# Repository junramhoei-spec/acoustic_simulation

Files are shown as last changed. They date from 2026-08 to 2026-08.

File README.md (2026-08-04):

# 🔊 Acoustic Shape Reconstruction V2 (음향 기반 컵 형상 역추적 프로젝트)

이 프로젝트는 **물 채움 시 수위 변화에 따른 음향 공명 주파수(Dip Spectrum / Ratio Transfer Function)** 데이터를 기반으로 컵의 **높이($) 및 3D 반지름 프로파일((z)$)**을 역추적하는 딥러닝 프레임워크입니다.

---

## 🌟 주요 기능 (Key Features)

1. **순방향 음향 공명 탐색기 (Forward Explorer)**
   - Transfer Matrix Method (TMM) 음향 관 모델링 기반 딥 스펙트럼 합성
   - 물 주입 시퀀스에 따른 음향 워터폴 스펙트로그램 시각화
2. **전문가 결합 모델 (Ensemble Prediction)**
   - 높이 전문가 ($ Expert: 
nn_sline_nodetach_bestH.pt)
   - 반지름 전문가 ($ Expert: 
nn_sline_uni.pt)
   - 25개 10mm 슬롯 피치 등가반지름 계단 프로파일 복원
3. **20종 실측 세션 자동 일괄 평가**
   - 실측 데이터셋 자동 로드 및 실시간 역추정
   - 음향 공명 스펙트로그램 + 참값(True GT) vs 예측(Pred) 1:1 시각화 비교

---

## 🚀 빠른 시작 (Quick Start)

### 1. 필수 패키지 설치
`ash
pip install torch numpy matplotlib streamlit pandas
`

### 2. Web GUI 대시보드 실행
`ash
streamlit run V2/app.py
`

---

## 📁 디렉토리 구조 (Repository Layout)

`
acoustic_simulation/
├── V2/                         # Streamlit 앱 및 핵심 역추적 파이프라인
│   ├── app.py                  # Streamlit 통합 웹 앱 실행 파일
│   ├── real_measured_json_all/ # 20종 실측 JSON 데이터셋
│   └── create_report_docx_v4.py# 보고서 생성 스크립트
├── v2/                         # 알고리즘 핵심 패키지
│   ├── config.py               # 음향 물리 상수 및 모델 설정
│   ├── combine.py              # 앙상블 조합 추론기 (CombinedPredictor)
│   ├── forward/                # TMM 순방향 시뮬레이터 (tmm.py)
│   └── data/                   # 데이터 로더 및 전처리 모듈 (loader.py, shapes.py)
├── dataset/
│   └── models_v2/              # 사전 학습된 PyTorch 체크포인트 (.pt)
├── README.md
└── .gitignore
`

---

## 📧 문의 및 정보
- Contact: junramhoei@gmail.com

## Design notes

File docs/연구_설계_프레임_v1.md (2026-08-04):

# 음향 기반 내부 형상 추정 연구 — 설계 프레임 (v1)

> 살아있는 설계 스펙 문서. CNN·RNN·PINN 및 데이터 생성이 공통으로 따르는 단일 기준.
> 작성 맥락: 컨설팅 대화 정리본. 결정된 항목과 미결(TODO)을 구분해 기록.
> 갱신 2026-07-02: §5 감쇠·관측량 결정, §9 도메인 적응 전략(시그니처 2성분·on-the-fly 증강·현장 미세조정) 확정.
> 갱신 2026-07-02(b): §4 형상 범위 확장(실물 컵 포섭), §5 생성 대역 50~7kHz + crop, §6 전처리 확정, §7 출력 그리드 10mm×25슬롯(장치 비종속).
> 갱신 2026-07-05: §8 CNN 베이스라인 확정(base_ratio_v2 + H 선형 보정). H-r 시소는 옵티마이저 처방 불응 → 구조적 간섭으로 판정, RNN 단계 이행.

---

## 0. 핵심 명제 (Thesis)

> **음향(반사/방사) 기반 내부 형상 측정은 해가 비유일(ill-posed)하다. 수위를 변화시키며 여러 경계조건에서 측정하면 유일성이 복원된다. 이 well-posed 역문제를 딥러닝(CNN → RNN → PINN)으로 해결한다.**

- 선행분야: 음향 반사측정(acoustic reflectometry), 음향 비강측정(acoustic rhinometry/pharyngometry) — "음향으로 단면적 복원"을 하지만 **비유일성**이 약점.
- 본 연구의 신규성: **물채움을 유일성 복원 장치로 도입**한 이중 모달리티. (연속방정식은 유일성 회복의 물리적 근거 중 하나.)

---

## 1. 측정 원리 (이중 채널)

정유량 `Q`(일정하고 **알려진 값**)로 채울 때, 수면 높이 `h(t)`에서:

```
dV/dt = A(h)·dh/dt = Q   →   A(h) = Q / (dh/dt)
```

- **음향 채널**: 공명 → 공기기둥 길이 → **수위 h(t)** 측정 (+ 수면 위 형상).
- **유체(연속방정식) 채널**: 알려진 Q + h(t) → **수면(잠긴) 단면적 A(h)**.
- 물이 바닥→위로 지나며 모든 높이가 한 번씩 수면이 되므로, **연속방정식만으로 전체 A(z) 복원 가능**. 음향은 수위 제공이 주임무, 수면 위 형상 역산은 교차검증.
- 노이즈 강건화: `A(h)` 를 미분(dh/dt) 대신 **적분 제약** `∫A dh = Q·t` 형태로 사용.

**⚠ 정유량 Q 기지(旣知)는 선택이 아니라 연구의 토대.** (수위-부피 정규화는 이 토대를 파괴하므로 금지 — 아래 4장 참조.)

---

## 2. 일반화의 논리 (미지 공동에서 왜 되는가)

- 블랙박스 "스펙트로그램 → 반지름" 회귀는 **학습분포 밖(OOD) 실제 공동에서 일반화 안 됨.**
- **연속방정식은 형상과 무관한 보편 물리** → 어떤 미지 공동에서도 성립.
- 따라서 ML 역할 재정의: ML은 **"공명 → 수위/공기기둥 길이"** 라는 일반화 잘 되는 하위문제를 맡고, 단면적은 연속방정식이 해석적으로 제공. PINN이 두 물리를 함께 강제.

---

## 3. 물리적 장치 (기준 형상) — 자동화 검증/교정 리그

- 링: 두께 **15mm**, **최대 10개** 적층. 링 스택 높이 = (링 수)×15mm, 최대 **150mm** (가변) = **추정 대상 라벨 높이**.
- 링 내경 6단계: 2cm~8cm → 반지름 **{10, 16, 22, 28, 34, 40} mm**.
- **상단 확장(고정)**: 링+피스톤이 5mm 하강, 100φ 아크릴 원통은 고정 → 최상단 링 위 **r=50mm·높이 5mm** 구간이 **입구 바로 안쪽에 항상 존재**. 이를 음향 공동에 **포함** → **음향 공동 높이 = 링스택 + 5mm, 최대 155mm**. (이 5mm는 추정 라벨이 아니라 순방향에 늘 들어가는 **기지 고정 세그먼트**.)
- 마이크: 무지향성, 컵 축 중앙, **음향 공동 상단(입구)에서 10mm 위** (= 바닥 기준, 10링이면 165mm). 평균 관구효과 기준 압력 마디 근처 → 공명에서 **딥(dip)** 측정.
- **장치의 역할**: 실험 **자동화** 시연 + 정답 아는 형상으로 방법 **검증** + 실제 마이크/스피커/공간 **시그니처 수집**(도메인 적응용). 이산 스텝은 과도기 단계.

---

## 4. 데이터 생성 프로토콜 (결정)

- **형상 생성 (✅ 2026-07-02 확장)**: 연속 랜덤 프로파일, **r ∈ [5, 50]mm, H ∈ [30, 250]mm** — 텀블러·소주병·맥주잔·와인잔 등 실물 컵 포섭. **학습 분포 ⊃ 링 장치 범위** (장치는 분포 안의 정답 아는 부분집합 = 평가·시연용). 데모 *평가*만 6단 이산 + 선택적 스냅. TODO: 비현실 극단 조합(초소형 부피 등) 배제용 타당성 제약.
- **물채움 (✅ 2026-07-02 확정, ΔV 스터디 근거: `v2/validation/dv_study.png`)**:
  - **프로토콜 v1 (1차 데이터셋)**: **고정 ΔV = 10mL**, 정지 기준 = **잔여 공기기둥 30mm**(부피%가 아닌 높이 기준 — 넘침 마진이 전 컵 균일), **최대 128스텝 캡**, **최소부피 제약 = 40mL**(스텝≥5 보장). 스텝 수는 결과값(가변, 마스킹).
  - **프로토콜 v2 (측정 기반 적응형, 베이스라인 후 도입)**: 첫 붓기 10mL → 직전 붓기의 수위 변화를 **측정으로** 추정(LPC/딥 이동) → **등-Δh(목표 8mm)**가 되도록 다음 ΔV 조절. 스텝 ≤ ~31로 유계, 전 높이 균일 샘플링, 실전 실행 가능(정답 불요). 선행 발명(LPC 자동 물멈춤)이 컨트롤러로 편입.
  - **부은 부피 V_i 는 "누설"이 아니라 연속방정식 측정 채널** → 입력으로 사용 정당. 가변 붓기(v2)도 V_i 입력이 원생 지원. (스케일/대략 높이는 유체 채널, 정밀 형상은 음향 채널.)
- **높이 하한**: H=30mm이면 빈 공동 f₁≈2.9kHz로 대역 내(단, 대역 내 모드 1개 — 짧은 컵일수록 정보 얇음을 인지). 링 장치는 최소 ≈3링부터.
- ❌ **금지**: "부피비율 등분(각 컵 자기 부피의 N등분)" — 절대 스케일/연속방정식 채널을 정규화로 파괴.

---

## 5. 순방향 시뮬레이션 (Forward)

- 1D 전달행렬법(TMM), **미분가능**하게 유지(향후 PINN 재사용). 폐-개, 물표면=강체.
- **마이크 응답 = B 정식 모델**: (공동 입구 위 **10mm**) 마이크 점 압력 = ① 스피커 직접장 + ② 입구 단극 재방사(`U_mouth ∝ p_입사/Z_mouth(f)`) 합. 공명에서 `Z_mouth` 최소 → 상쇄간섭 → **딥**. 상단 5mm 확장 반영.
- **감쇠 (✅ 결정 2026-07-02)**: **Kirchhoff 경계층 손실 공식으로 확정** — 점성·열 손실, 상수까지 알려진 표준 물리라 튜닝 파라미터 없음. 구현 = 파수를 복소수로(`k → (ω/c)(1-jα)`, `α ∝ √f/(r·c)`), TMM 구조·미분가능성 유지. 무손실 TMM의 면도날 피크/500빈 샘플링 문제도 함께 해결. (대기 흡음은 경계층 대비 미미 → 생략 가능.)
- **관측량 (✅ 결정 2026-07-02)**: 시뮬-실측 공통 기초 = **컵 없음 기준 측정** — 피스톤 최상단 = 공동 깊이 0 = 평평한 강체면. 자동화 사이클에 포함해 매 세션 확보. 이 기준으로:
  - **주 전략**: 절대 스펙트럼 + **시그니처 곱하기 증강**(§9) 학습 → 실녹음 직접 추론. 전날 현장 시그니처로 미세조정.
  - **안전망**: **비율 전달함수** `H_cup(f)/H_ref(f)` — 스피커·마이크·룸 특성(S·R·M)이 약분되어 시뮬이 직접 계산 가능한 순수 물리량. 현장 재학습 불필요. (한계: 덧셈성 소음은 약분 안 됨 → 잔여물 주입 증강 필요.)
  - 두 방식은 한 파이프라인의 증강 옵션 두 개로 구현(별도 구현 금지).
- **유효대역 (✅ 결정: 1D 유지)**: on-axis 대칭 셋업에선 각 모드 (1,0)이 축상 마디라 가진·감지 안 됨 → 실질 한계는 첫 반경 모드 `≈ 0.61·c/a`. 수치 검증 결과 r≤4cm에서 첫 반경 모드 ≥ **5,259Hz(대역 밖)** → **50~5000Hz에서 1D = 2D. 1D 유지.** 근거: `docs/analysis/1d_vs_2d_validband.{py,md,png}`. 재검토: 대역>5kHz 또는 비원형 단면.
- **생성 대역 (✅ 결정 2026-07-02)**: 시뮬 생성 **50~7000Hz, 700빈**(저역 빈 폭 ≈10Hz 유지). r 상한 50mm 확장으로 첫 반경 모드가 넓은 컵에서 대역 내 진입: r=50→4.2kHz, r=40→5.2kHz, r=35→6.0kHz, r=30→7.0kHz. **4.2kHz 이하는 전 형상에서 1D 유효.** 그 위 대응: (i) 학습 사용 대역 = **crop 하이퍼파라미터**(기본 5kHz), 리그 최광폭 링 실측 어블레이션으로 확정. (ii) 4~7kHz **가짜 딥 랜덤 주입**(도메인 랜덤화, §9)으로 미모델 반경 모드에 대한 과신 방지. 고차 모드의 가치: 축방향 해상도(λ/4 ≈ 12~17mm) + 거의 찬 상태(짧은 공기기둥 12~21mm)의 유일 공명이 4~7kHz에 존재.

---

## 6. 전처리 (✅ 2026-07-02 확정)

1. **스펙트럼 = log → z-score, "시퀀스 전체" 단위** — 게인은 세션 상수이고 곱셈이므로, log 후 평균 제거로 정확히 소거됨. **스텝별 개별 표준화 금지**: 스텝 간 진폭 관계(딥 깊이 변화 등)는 물리 신호라 보존해야 함. 평균 1개·표준편차 1개/샘플.
2. **V_i = 고정 상수(1L)로 정규화** — 샘플별 최대부피로 나누기 **금지**(절대 스케일 파괴 = §4 금지사항 "부피비율 등분"과 동일 오류).
3. **라벨 = 물리 상수 min-max**: r ∈ [5, 50]mm, H ∈ [30, 250]mm (§4 생성 범위와 동일 상수, 설정 파일에 고정). **정규화 기준을 데이터 통계에서 뽑지 말 것** — 구 코드의 spec_min/max 방식은 데이터셋 재생성 때마다 기준이 흔들려 모델-데이터 불일치 사고의 원인.
4. **가변 길이 = 패딩 + 마스크** — 무효 스텝/슬롯을 0 값으로 때우지 않고 0/1 마스크로 명시(모델 입력·손실 계산 양쪽에 적용).
5. 주파수 대역: §5의 crop 하이퍼파라미터를 따름.

---

## 7. 입출력 규격 (CNN/RNN/PINN 공통) — ★ 못박을 것 ★

- **입력**:
  - 스펙트럼 시퀀스 (가변 길이 → **마스킹**).
  - 스텝별 부은 부피 `V_i` (연속방정식 채널, 정당한 측정 입력).
- **출력 (✅ 2026-07-02 개정)**:
  - 반지름 **25슬롯 그리드**(피치 10mm, 절대 높이 0–10, …, 240–250mm) + **높이 H**.
  - 그리드 = **출력 샘플링 해상도**(≈물리 한계 λ/4)일 뿐 형상 가정 아님. **장치 링 두께 15mm와 비종속.** 라벨 = 각 밴드 **평균 단면적의 등가반지름** `√(Ā/π)` (연속방정식이 측정하는 양과 동일 형태).
  - 유효 슬롯만 손실 계산(**마스킹**). 연속 회귀 유지(분류 아님).
  - 리그 평가: 그리드-링 정렬 불필요. 예측 r(z) vs 정답 r(z) **함수 대 함수 비교**.
- **역할 분담**: 대략 스케일/높이 ← 유체(V), 정밀 형상(10반지름) ← 음향.

---

## 8. 모델 사다리 (CNN → RNN → PINN)

각 단계 정확도 향상 = 기여의 증거. **세 단계가 7장 규격을 공유**해야 비교가 깨끗함.

- **CNN (✅ 베이스라인 확정 2026-07-05)**: `base_ratio_v2.pt` + H 선형 보정(자동 내장). 테스트: r_MAE **2.47mm**, H_MAE 9.13 → 보정 후 **4.38mm**.
  - **판정 근거**: ① 높이 산점도가 상관 0.9977의 팽팽한 직선 = 정보는 충분, 눈금(스케일)만 압축 — 정보 부족 아님. ② H·r 검증 손실이 시소(멀티태스크 간섭) — AdamW+wd+코사인 처방에 불응, 기울기가 0.84 → ~1.12로 학습마다 뒤집힘 → 옵티마이저가 아닌 **공유 몸통의 구조적 간섭**으로 판정. ③ 보정은 계측기 교정과 동일한 표준 절차(검증셋 적합, 테스트셋 비오염).
  - CNN 몸통 추가 튜닝은 중단(RNN에서 몸통이 바뀌므로 이월 안 됨). 시소의 구조적 해소는 RNN 설계에 내장(`docs/RNN_설계_초안_v1.md`).
  - 재발 방지: train.py가 에폭별 성분 로그(l_r/l_h)를 `{name}_trainlog.csv`로 무조건 저장 + 체크포인트 history 전체 보존(2026-07-05 패치).
- **RNN(LSTM)**: 물채움을 시계열로. 어블레이션으로 "순서가 기여하나" 검증
  (셔플 테스트 / 역방향·양방향 / 마지막-스텝-only vs 전체 풀링·어텐션 / **구간별(상·하부) 오차**).
  - 물리 예측: 바닥 형상은 초기(긴 기둥) 스텝에서만 보임 → 역방향/양방향은 **바닥 반지름 오차**를 특히 줄여야 함.
- **PINN**: 미분가능 TMM 물리층. 손실 =
  1. 음향 일치: `TMM(공기기둥[h(t),H], A) ≈ 측정 스펙트럼`
  2. 연속방정식 잔차: `∫A dh = Q·t`
  3. 수면 위(음향)·아래(연속) A 겹침 일치.

---

## 9. 검증 설계 + 도메인 적응 전략 (✅ 2026-07-02 확정)

- 도메인 갭 분리: **시뮬 계단컵** 정확도 vs **실측 계단컵** 정확도 → 순수 sim→real 갭.

### 9.1 시그니처 = 2성분 분리 수집
- **곱셈 성분** (스피커·마이크·룸 전달특성 S·R·M): 각 공간에서 **스윕 측정 + 기준형상(피스톤 최상단)으로 나눠 추출**. cavity 응답은 제외.
- **덧셈 성분** (배경소음): 각 공간에서 **그냥 녹음** (복도 백색소음, 관중 웅성거림 등).
- 라이브러리: 실험실/강당/밴드실/복도 등 여러 공간에서 두 성분을 각각 채취. 곱셈 성분의 가상 확장은 pyroomacoustics 등 룸 시뮬레이션으로(스피커로 공간음 재생·녹음하는 방식은 덧셈 성분에만 유효 — 부록 A).

### 9.2 on-the-fly 증강 (데이터에 굽지 않고 로더에서 실시간)
- 매 샘플마다 랜덤 조합: **(룸 시그니처 1개 곱하기) + (소음 1개 더하기) + (섭동: 게인·스펙트럼 기울기·미세 시프트·온도 15~30°C·마이크 높이 d_mic ±1mm)**.
  - d_mic 지터 근거: 딥 위치의 근접장 이동 민감도 ≈ 1.7Hz/mm(모드1, 빈 폭 10Hz 대비 소폭) → 지그 공차 흡수용.
- **스텝 서브샘플링 증강 (✅ 2026-07-02)**: 저장된 풀 시퀀스(10mL 격자)에서 로더가 랜덤 부분수열을 추출해 학습(V_i는 누적값 그대로). 효과: ① 가변 간격 V_i 패턴이 학습분포 안으로 → **적응형 프로토콜 v2(10mL 배수 양자화) 추론을 v1 데이터셋 하나로 커버**(재생성 불필요), ② 스텝 번호에 기대는 지름길 차단 → V_i(유체 채널)를 실제로 읽도록 강제.
- 라이브러리 몇 개 × 조합 = 수백 가상 환경. 시그니처 파일 교체만으로 재증강 가능(전날 밤 작업 최소화).

### 9.3 학습 전략
- **베이스 모델 1개**: 전 라이브러리 혼합(멀티컨디션) 학습. 환경별 전용 모델보다 미지 환경 일반화 우수(부록 A).
- **현장 미세조정**: 전람회 전날 설치 → 현장 시그니처·소음 채취(자동) → 베이스에서 fine-tuning(낮은 LR, 짧게, 현장:라이브러리 혼합 유지로 망각 방지).
- **안전망**: 비율 방식(§5) 사전 학습 모델 지참 — 현장 재학습 실패 시 대체.
- **어블레이션(발표 자료 겸용)**: ① 환경별 전용 vs 혼합 베이스, ② 절대+시그니처 vs 비율, ③ 미세조정 전 vs 후.

---

## 10. 활용 방안 ("물이 차/빠지고, 내부 형상이 궁금한 곳")

- 탱크류(연료·화학·물): 정상 충전/배출 중 내부 형상·퇴적·파울링 진단.
- 우물·시추공·카르스트/동굴: 자연 수위 변동을 스캔.
- 시스턴·정화조·변기 물탱크: 반복 충전/배출.
- 관악기 보어 비파괴 내경 측정(원 컵 연구의 정통 응용).
- (원거리) 하수/배수 협착 위치·정도 — 여러 응용 중 하나로 위치.
- 셀링 포인트: **"평소 물을 채우고 빼는 김에, 마이크·스피커만 붙이면 내부 형상을 덤으로 안다."**

---

## 11. 데모

- 최종: 링 자동화 기계 + **소주병 등 실물**.
- 방점: **실험 자동화**(손으로 몇 개 찍은 게 아니라 측정 전체를 자동화).

---

## 12. 미결 결정 / TODO

- [x] 마이크 B 정식 모델 v1 구현(2026-07-02, `v2/forward/tmm.py`): 직접음+이미지 반사 / 배플 피스톤 축상 정확해 재방사 / 정확 방사 임피던스(J1+Struve). 검증: 임피던스 공명 PASS, 딥의 근접장 이동(d_mic=10mm에서 +14%)이 원거리에서 공명으로 단조 수렴 PASS. → 남은 일: 리그 실측으로 근접장 이동량 실증(Phase 6).
- [x] 감쇠 모델 결정(Kirchhoff 경계층, 2026-07-02) → 구현·검증 남음.
- [x] 관측량·도메인 적응 전략 확정(§5, §9 / 2026-07-02) → 구현 남음.
- [ ] 시그니처 라이브러리 채취 계획(공간 목록·측정 절차·저장 포맷).
- [ ] on-the-fly 증강 로더 구현(곱셈·덧셈·섭동, 비율/절대 모드 스위치).
- [ ] 현장 미세조정 리허설(전날 밤 드릴 전체를 학교에서 1회 예행).
- [x] ΔV·정지기준 확정(2026-07-02, `v2/data/dv_study.py`): v1 = 고정 10mL + 공기기둥 30mm 정지 + 최소부피 40mL + 128스텝 캡.
- [ ] 프로토콜 v2: 등-Δh(8mm) 적응형 컨트롤러 — 시뮬 구현(추정 노이즈 포함) + v1 대비 어블레이션.
- [ ] 대역 crop 어블레이션(4k/5k/7k) — 리그 최광폭 링 실측으로 반경 모드 실재 확인 포함.
- [ ] Phase 6 실험 추가: 마이크 높이 스윕(10/30/60/100mm)으로 딥 위치 수렴 곡선 실측 → 관측 모델(근접장 이동) 실증. 모델 예측(15cm/3cm 원통): 557→524→504→494Hz.
- [ ] 가짜 딥 증강(4~7kHz) 구현.
- [ ] 1D 유효성 스크립트 r=50mm/H=250mm 재실행(`docs/analysis`).
- [x] CNN 베이스라인 확정(2026-07-05): base_ratio_v2 + H 보정. 시소 = 구조적 간섭 판정 → RNN 이행(§8).
- [ ] RNN 구현(`docs/RNN_설계_초안_v1.md`): H 헤드 gradient 분리 내장, 시소 재발 여부를 성분 로그로 검증.
- [ ] 모델 구조 확정(셔플/역방향 어블레이션 결과 후).
- [ ] 전처리(§6 5개 항목) 구현.
- [ ] 7장 입출력 규격을 코드 인터페이스로 고정.

- [ ] **(v3 구상, 2026-07-05) 연속 주수 모드**: 정지-측정 스텝 대신 정유량 Q로 연속 주수하며 짧은 반복 스윕(또는 연속 가진 + 슬라이딩 창 전달함수). 타당성 근거: 분석 창 0.1~0.2s(빈폭 10Hz 확보) 동안 수위 상승 0.03~0.5mm → 넓은 컵은 스미어링 무시 가능, 좁은 컵·만수 근처(감도 f/L ≈ 95Hz/mm@L=30mm)는 초과 → **적응형 유량 제어**(등-Δh 컨트롤러의 연속판, LPC 수위 추정으로 Q 조절) 필요. 물소리 = 덧셈 성분(§9.1)으로 증강 라이브러리에 실녹음 투입, 벽면 주수로 최소화. 기존 설계가 이미 절반 준비: V_i 누적 입력 원생 지원 + 스텝 서브샘플링 증강 + 적응형 프로토콜 v2 컨트롤러. §10 활용처(탱크/우물 = 자연 연속 유동)와 서사 정합. **전제: v1(정지 스텝) 리그 검증 통과 후 착수.**

---

### 부록 A. 지난 논의에서 교정된 오해(기록용)
- "부피비율 등분 샘플링" → **금지**(연속방정식 채널 파괴). 정유량+고정 ΔV로.
- "부은 부피 입력 = 정답 누설" → **아님.** V는 유체 측정 채널(정당). 형상은 여전히 음향에서.
- "높이/L_air 입력" → 금지(정답 파생). **V(부은 부피)만** 입력.
- "하수구 유량계가 메인" → 아님. **음향 형상측정의 유일성 복원**이 핵심 명제.
- "1D는 2500Hz까지만 유효" → 과장. on-axis라 실질 한계는 첫 반경 모드 ≈0.61c/a. **50~5000Hz에서 1D 유효(수치 검증, `docs/analysis/1d_vs_2d_validband`)** → 1D 유지, 2D 불필요.
- "2D 축대칭 → 원/사각 구별" → 아님. 축대칭은 원형을 가정. 단면 모양 구별은 각 모드(m≥1)=완전 3D 필요(+on-axis 마디+대역 밖으로 삼중 장벽).
- "스피커로 유튜브 공간음을 재생해 룸 시그니처 생성" → **덧셈 성분(소음)으로만 유효.** 곱셈 성분은 재생해도 실제 방+재생 스피커의 응답이 찍힘. 가상 룸 전달함수는 pyroomacoustics 등 물리 시뮬레이션으로.
- "부피 등분 + ΔV를 입력으로" → 정보 파괴는 해소되나 **정답 누설(label leakage)**: ΔV=V×0.95/N은 정답 파생값 → 모델이 부피를 소리 없이 역산하는 지름길 학습 → 실전 붕괴. 게다가 실전에서는 V를 몰라 등분 불가(닭-달걀).
- "지수 증분(10,20,40...)" → 누설·닭달걀은 없으나 압축 좌표가 틀림: 마지막 붓기가 컵의 절반 → **위쪽 해상도 붕괴** + 스냅샷 수 급감. 올바른 좌표는 높이 → **등-Δh 적응형**(§4 v2)이 지배해.
- "환경별 전용 모델을 만들어 상황에 맞게 선택" → 혼합(멀티컨디션) 학습 1개 + 현장 미세조정이 일반적으로 우수(전용 모델은 시그니처 과적합 + 환경 판단이 추가 오류원). 전용 vs 혼합은 어블레이션으로 남김.
- "출력 슬롯 = 장치 링 두께 15mm" → 아님. 출력 그리드는 답안의 **샘플링 해상도**로, 물리(λ/4 ≈ 12~17mm + 연속방정식 채널)가 정하는 설계값(10mm 채택). 형상 생성은 범위 내 완전 연속·랜덤이며 장치와 비종속.

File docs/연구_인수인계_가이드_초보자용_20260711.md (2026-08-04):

# 음향 형상 추정 연구 — 초보자용 인수인계 가이드 (2026-07-11)

> 이 문서는 딥러닝을 처음 접하는 사람(학생 포함)이 이 연구를 이어받아
> 진행할 수 있도록 쓴 안내서다. 세 부분으로 되어 있다:
> ① 연구가 뭘 하는 건지 → ② 용어 사전 → ③ 지금까지 결과와 다음 할 일.

---

## 1. 이 연구는 무엇을 하는가 (3분 요약)

**목표: 컵(용기)에 물을 조금씩 부으면서 나는 소리만 듣고, 컵의 속 모양을 알아맞히기.**

```
물을 한 스텝(ΔV) 붓는다
   → 스피커로 소리를 쏘고 마이크로 녹음한다
   → 공기 기둥의 공명 때문에 특정 주파수에서 소리가 움푹 꺼진다(딥, dip)
   → 물이 찰수록 공기 기둥이 짧아져 딥의 위치가 옮겨간다
   → 이 "딥의 이동 패턴" 시퀀스를 신경망에 넣으면…

   신경망의 답: ① 컵 전체 높이 H (숫자 1개)
               ② 바닥부터 10mm 층마다의 반지름 r(z) (숫자 25개 = "슬롯")
```

- 실제 컵 데이터를 모으기는 힘들어서, **물리 시뮬레이터(TMM)** 로 가짜 데이터를
  대량 생성해 학습한다. (`v2/forward/tmm.py`가 그 시뮬레이터)
- 시뮬레이션으로 배운 모델을 **실제 녹음**에 적용하는 것이 다음 큰 관문이다.
  이걸 **sim-to-real(심투리얼)** 이라고 부른다.

## 2. 용어 사전 (이 프로젝트에서 실제로 쓰는 말만)

| 용어 | 뜻 |
|---|---|
| **학습(training)** | 모델에게 문제(스펙트럼)와 정답(형상)을 반복해서 보여주며 가중치를 조정하는 과정. `v2/train.py` |
| **에폭(epoch)** | 전체 학습 데이터를 한 바퀴 다 보는 것. 보통 30바퀴 돌린다 |
| **loss(손실)** | "지금 얼마나 틀렸나"의 점수. 학습은 이걸 줄이는 방향으로 진행 |
| **train/val/test 분할** | 데이터를 80/10/10으로 나눔. train=공부용 문제집, val=모의고사(학습 중 실력 확인·보정계수 산출), test=수능(마지막에 딱 한 번 채점) |
| **MAE** | 평균 절대 오차. \|예측−정답\|의 평균. **H_MAE**는 높이 오차(mm), **r_MAE**는 반지름 오차(mm). 작을수록 좋다 |
| **체크포인트(.pt)** | 특정 시점의 모델 가중치 저장 파일. `dataset/models_v2/`에 있음. `이름.pt`=종합점수 최고 시점, `이름_bestH.pt`=높이만 최고인 시점 |
| **과적합(overfitting)** | 문제집(train)만 달달 외워서 모의고사(val) 점수가 오히려 나빠지는 현상 |
| **시소 현상** | 한 모델이 H와 r을 같이 배울 때 몸통(공유 층)을 서로 뺏으며 한쪽이 좋아지면 다른 쪽이 나빠지는 것. 이 연구의 핵심 골칫거리였음 |
| **detach** | H 머리로 가는 학습 신호를 몸통에서 끊는 스위치. ON=몸통은 r 전용(H가 굶음), OFF=같이 씀(시소 위험). 실험 결과 **높이에는 OFF가 유리** |
| **continuity 손실** | "예측한 컵 모양에 실제 부은 물 부피가 들어가야 한다"는 물리 상식을 loss에 추가한 것. 일반 정규화(dropout 등)보다 과적합 억제에 훨씬 효과적이었음 |
| **H 보정(calibration)** | 모델의 높이 눈금이 일정하게 밀려 있을 때 1차식(a×예측+b)으로 펴는 것. val에서 a,b를 구함. 산포(들쭉날쭉)는 못 고침 |
| **reality gap** | 시뮬과 실측의 미묘한 차이. 시뮬 점수를 극한까지 쥐어짜면 오히려 실측에서 나빠질 수 있음 → 시뮬 최고점수가 목표가 아님 |
| **테스트타임 정제** | 학습이 끝난 뒤, 예측 하나하나를 "물리 시뮬레이터에 다시 넣어 측정과 맞을 때까지 미세 조정"하는 것. 미분가능 TMM(`tmm_torch.py`)이 필요 |
| **미분가능(differentiable)** | "출력을 이만큼 바꾸려면 입력을 어느 쪽으로 움직여야 하나"(gradient)를 자동 계산할 수 있는 형태. PyTorch로 짜면 공짜로 얻는다 |

## 3. 지금까지의 실험 결과 (2026-07-07까지, 시뮬 데이터 기준)

| 모델 | r_MAE | H_MAE(보정 후) | 한 줄 평 |
|---|---|---|---|
| CNN `base_ratio_v2` | 2.47mm | 9.13→**4.38mm** | 보정이 잘 먹음. H 기준 기록 보유자 |
| RNN detach-on `rnn_ratio` | **1.74mm** | 12.1→11.7mm | r은 최고지만 H는 산포라 보정 무력 |
| RNN detach-off `rnn_ratio_nodetach` | 2.22mm | raw 6.2mm (1에폭 시점) | 19에폭에서 중단, 보정·TEST 미산출 ← **evaluate.py로 채점하면 됨** |
| RNN+continuity `rnn_continuity` | ~1.5–1.8mm | ~11mm | 30에폭 과적합 없이 안정. **r 전문가 확정** |
| dropout/wd/lr 스윕 (`*_reg`, `d128`) | — | — | 전부 과적합. 실패 기록으로만 의미 |

**핵심 교훈 3가지**
1. 높이는 detach OFF가 유리 (보정이 먹히는 "상관 있는" 출력이 나옴)
2. 물리 기반 continuity 손실 > 일반 정규화 (과적합 억제·r 정확도 모두)
3. 선형 보정은 눈금만 펴고 산포는 못 편다

**현재 전략: 전문가 결합 + 테스트타임 정제**
```
[H 전문가: detach-off 모델] ──→ H (보정 적용)
                                    ↘
                                     (r, H) 결합 ──→ [테스트타임 정제] ──→ 최종 형상
                                    ↗                (미분가능 TMM으로
[r 전문가: rnn_continuity] ──→ r(z) 25슬롯           물리적으로 봉합)
```
시소의 근원(몸통 공유)을 모델 분리로 원천 차단하고, 둘의 물리적 불일치는
정제 단계가 자동으로 꿰맨다.

## 4. 오늘(7/11) 새로 만든 도구 3개

### ① `v2/evaluate.py` — 체크포인트 채점기
아무 .pt 파일이나 넣으면 보정계수 적합 → 보정 후 TEST 점수 + 슬롯별 r_MAE를 출력.
```
python v2\evaluate.py --ckpt dataset\models_v2\rnn_ratio_nodetach_bestH.pt --save
```
`--save`를 붙이면 보정계수를 파일 안에 기록해 두어 combine.py가 재사용한다.

### ② `v2/combine.py` — 전문가 결합기
H 전문가 + r 전문가를 한 팀으로 묶어 시뮬 테스트셋을 채점한다.
```
python v2\combine.py --h_ckpt dataset\models_v2\rnn_ratio_nodetach_bestH.pt ^
                     --r_ckpt dataset\models_v2\rnn_continuity.pt
```
성공 판정: H_MAE ≤ 4.38mm(CNN 기록)와 r_MAE ≤ ~1.8mm(continuity 기록)를 동시 달성.
실측 데이터 1개 추론용 `CombinedPredictor.predict()`도 들어 있다(링 검증 때 사용).

### ③ `v2/forward/tmm_torch.py` — 미분가능 물리 시뮬레이터
테스트타임 정제의 심장. NumPy 원본(tmm.py)과 수치 일치 검증 완료:
- 스펙트럼 오차 최대 2.3e-2 (전부 스트루브 함수 근사 기인, 딥 바닥에만 국한.
  동일 근사 조건에서 구현 차이는 1e-8 이하로 확인)
- gradient는 유한차분과 1.8e-5 수준 일치
```
python v2\forward\tmm_torch.py     ← 아무 컴퓨터에서나 자가 검증 실행
```

### 오늘 발견한 함정 2개 (같은 실수 방지용 기록)
1. **`torch.special.bessel_j0/j1`은 미분 규칙이 없다** (torch 2.13 기준).
   에러 없이 gradient가 조용히 누락된다. → tmm_torch.py에 도함수 공식
   (J₀′=−J₁, J₁′=J₀−J₁/x)을 직접 등록해 해결했다. 절대 원복하지 말 것.
2. **train.py의 `--c_weight` 기본값이 1.0** (continuity 손실 자동 ON).
   과거 nodetach 실험(7/6)은 continuity 도입 전이라, 그때와 같은 조건으로
   재학습하려면 `--c_weight 0`을 명시해야 한다.

### 환경 주의사항 (OneDrive 폴더에서 작업할 때)
- 코드를 고쳤는데 반영이 안 되는 느낌이면 → 프로젝트 안의 `__pycache__` 폴더를
  지워라. OneDrive 동기화가 mtime을 꼬이게 해서 파이썬이 옛날 캐시를 쓸 수 있다.
- `.venv`는 동기화 제외 상태 유지. CUDA 파이썬은 시스템 파이썬 사용
  (`python -c "import torch;print(torch.cuda.is_available())"` → True 확인).

## 5. 다음 할 일 (집/다른 데스크톱에서, 순서대로)

```
# 0. 사전 점검
python v2\train.py --help        ← --c_weight 옵션 보이면 코드 최신
python -c "import torch; print(torch.cuda.is_available())"   ← True

# 1. 기존 bestH 체크포인트부터 채점 (재학습이 필요한지 먼저 판단!)
python v2\evaluate.py --ckpt dataset\models_v2\rnn_ratio_nodetach_bestH.pt --save
python v2\evaluate.py --ckpt dataset\models_v2\rnn_continuity.pt

# 2-a. 1의 보정 후 H_MAE가 4.38mm(CNN 기록)보다 좋으면 → 재학습 생략, 바로 3으로
# 2-b. 나쁘면 → H 전문가 재학습 (continuity 끄고 순수 nodetach 재현)
python v2\train.py --model rnn --no_detach --c_weight 0 --name rnn_h --epochs 30 --workers 4
python v2\evaluate.py --ckpt dataset\models_v2\rnn_h_bestH.pt --save

# 3. 전문가 결합 채점
python v2\combine.py --h_ckpt <1 또는 2에서 고른 H 전문가.pt> ^
                     --r_ckpt dataset\models_v2\rnn_continuity.pt

# 4. (다음 세션에서) 테스트타임 정제 루프 작성 — tmm_torch.py 준비 완료
# 5. (리그 준비되면) 링 실측 검증
```

원 계획서: `내일_sim2real_실행계획.md` (7/8 작성, 아래 수정사항 반영해서 읽을 것)
- Step 3의 "미분가능 TMM = v2/forward/tmm.py"는 오기 — tmm.py는 NumPy라 미분 불가.
  오늘 만든 `tmm_torch.py`가 그 역할. ✔ 해결됨
- Step 1 학습 명령에 `--c_weight 0` 누락 — 위 함정 2번 참고.
- Step 1↔2 순서는 "평가 먼저, 재학습은 필요할 때만"으로 뒤집는 게 경제적.

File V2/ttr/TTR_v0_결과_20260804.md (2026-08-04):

# TTR(테스트타임 정제) v0 프로토타입 — 리그 10컵 첫 실측 투입 결과 (2026-08-04 밤)

북극성 전략 2단계("미분가능 TMM으로 NN 예측을 실측 스펙트럼에 적합")의 첫 실동작.
`tmm_torch.py`(기검증)를 사용, 세션 작업물 `/home/claude/ttr/ttr_v0.py`.

## 설계
- 매개변수: H, r 슬롯 25개, **δ(리그 유효길이 연장, 입구 반지름 유지 세그먼트)** — 오늘
  발견한 리그 ΔL(+10mm, 원인 미상)을 원인 규명 전에 흡수하기 위한 자유 매개변수
- 초깃값: NN 전문가 결합 예측, δ=10mm
- 손실: 스텝 간 중앙값 차감 잔차 스펙트럼(100~3200Hz) MSE + r 평활 정칙화
  (중앙값 차감 = 북극성 문서의 전처리 1순위 — 정적 라인·배경 제거, 모드 궤적만 남김)
- 물리 앵커: 수위 h(V)를 현재 형상에서 미분가능하게 계산 → 궤적 기울기가 단면적 구속
- Adam 120회, 컵당 9~48초(CPU)

## 결과 (리그 10컵, 참값 대비)

| 컵 | 참H | NN H오차 | TTR H오차 | NN r_MAE | TTR r_MAE | δ 추정 |
|---|---|---|---|---|---|---|
| #14 일자105 | 105 | −1.5 | +1.5 | 3.61 | **1.31** | 11.0 |
| #15 벌120(좁은바닥) | 120 | −17.6 | −18.7 | 4.62 | 4.53 | 9.3 |
| #16 벌90 | 90 | +12.3 | **+6.6** | 7.19 | 8.15 | 8.3 |
| #17 오므90 | 90 | +23.3 | +19.3 | 2.56 | 2.72 | 8.1 |
| #18 오므120 | 120 | +20.8 | +20.8 | 4.58 | 5.13 | 9.4 |
| #19 볼록105 | 105 | −6.2 | −8.5 | 5.30 | 4.97 | 9.8 |
| #20 볼록120(좁은바닥) | 120 | −24.0 | −24.5 | 11.21 | 11.05 | 10.1 |
| #11 일자150r40 | 150 | +4.3 | +3.6 | 2.99 | **1.00** | 10.0 |
| #12 일자150r50 | 150 | +7.9 | +10.5 | 6.20 | 4.49 | 10.3 |
| #13 벌90오전 | 90 | +5.0 | **−0.9** | 4.14 | 3.35 | 8.4 |
| **평균** | | **12.3** | **11.5** | **5.24** | **4.67** | **9.5±0.9** |

## 판정 (정직 기록)

1. **δ의 세 번째 독립 확인**: 10컵 전부에서 δ가 8.1~11.0mm로 수렴 — 모드 추적(9.9~11.6),
   확장 쌍둥이 잔차와 전혀 다른 방법(전 스펙트럼 적합)이 같은 값을 찾음. 리그 ΔL≈10mm는
   이제 3중 확인된 사실. δ를 세션 공유 상수로 두는 개선(검증 원통에서 1회 적합 후 고정)이
   자연스러운 다음 단계.
2. **정보가 살아있는 컵에서는 뚜렷한 개선**: 원통 r_MAE 3.61→1.31, 2.99→1.00 (절반 이하),
   #13 H +5.0→−0.9, #16 H +12.3→+6.6.
3. **정보가 죽은 컵은 못 살림**: 좁은바닥(#15, #20 — 50mL 스텝이 바닥 건너뜀)과
   오므라드는형 H 편향(#17, #18 — +20mm대 유지)은 거의 불변. TTR은 스펙트럼에 없는
   정보를 만들어내지 못함 → 내일 10mL 재측정의 필요성을 역으로 뒷받침.
4. 평균 개선폭(H 12.3→11.5, r 5.24→4.67)은 아직 완만 — v0는 개념 검증. 개선 여지:
   딥 위치 가중 손실, 물리 적합 초깃값, 세션 공유 δ, continuity 앵커 on/off 어블레이션
   (검토메모의 계획 항목), 반복 수 증가.

## 남은 미스터리
오므라드는형(#17, #18)의 H +20mm 편향은 δ로도, TTR로도 안 빠짐 — 바닥은 잘 샘플링된
컵들이라 §4의 바닥 건너뜀과도 무관. 별도 원인(입구 좁아짐 구간의 모드 거동?) 추적 필요.

## 추가 (같은 날 밤 2차): "0스텝에 바닥 정보가 있는가" 검증 — 사용자 질문에서 출발

- **0스텝은 파이프라인 어디에서도 빠져있지 않음** (v_cum이 0부터 시작, NN·TTR 모두 사용).
- **이론 민감도**: #15의 빈컵 스펙트럼에서 참바닥(갈갈 r10) vs 오인바닥(r22) 차이 최대
  43dB(855~1074Hz 모드 구조) — 정보량 충분.
- **실측 확인(step0_check.png)**: 실측 빈컵 주 딥 1064Hz = 참형상 쌍둥이 1074Hz와 일치,
  오인바닥 쌍둥이 865Hz와 200Hz 분리 → **바닥 정보가 실측 데이터에 선명히 실재**.
- 따라서 TTR v0의 실패는 정보 부재가 아니라 설계 문제: ① 잔차 MSE가 딥 위치 신호를
  희석(0스텝 가중 ×5로도 부족), ② NN 초깃값이 지역 최솟값(특히 #20은 프로파일 상하 반전),
  ③ 균일 δ가 0스텝 적합을 방해.
- **신규 관찰**: #15의 0스텝은 δ=0 쌍둥이와 정합(δ10 쌍둥이는 985Hz로 어긋남). 원통들도
  0스텝 ΔL이 최소인 경향(#12: 5.5mm). → "리그 ΔL이 물이 있을 때 주로 나타나는가?"라는
  새 단서. 내일 판별 실험에 추가: 빈 원통 vs 물 조금 담은 원통에서 ΔL 비교.
- **TTR v1 설계 방향**: 딥 위치 기반 미분가능 손실, 다중 초깃값(NN+물리적합+반전),
  스텝 의존 δ, 0스텝을 바닥 앵커로 명시 사용.
- **프로토콜 제안**: 0스텝(빈컵)만 반복 촬영 횟수 상향(예: 5회 중앙값) — 바닥 정보의
  유일한 창이므로 SNR 투자 대비 효율 최대.

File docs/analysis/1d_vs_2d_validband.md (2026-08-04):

# 유효대역 검증 — 1D 평면파 TMM vs 2D 축대칭 (근거 노트)

> 최종 보고서용 근거. 재현: `python docs/analysis/1d_vs_2d_validband.py`
> 그림: `docs/analysis/1d_vs_2d_validband.png`

## 질문
측정 대역 **50~5000 Hz** 에서 1D 평면파 TMM이 우리 컵 크기(반지름 ≤4cm)에 대해 유효한가?
2D 축대칭으로 올리면 대역 안에서 결과가 달라지는가?

## 방법 (해석적 모드 비교)
폐-개 원형 실린더(공기기둥)의 고유모드를 해석적으로 계산해 비교. 실린더는 반경 차단주파수가 가장 낮은(=넓을수록 낮음) **최악 케이스**라 상한 검증에 적합.

- 축 방향(closed–open): `k_z = (2q-1)·π / (2·L_eff)`, `L_eff = L + 0.6133·a`
- 반지름 방향(rigid wall, m=0): `k_r = α_p / a`, `α_p` = `J0'`의 p번째 근
  - `p=0 → k_r=0` = 평면파(=1D) 계열
  - `p≥1` = 2D가 추가하는 **반경 모드**
- `f = c·√(k_z² + k_r²) / (2π)`, `c = 343.4 m/s` (20°C, `core/materials.py`와 동일)
- **on-axis 마이크는 각 모드(m≥1)를 못 봄**(축상 마디) → m=0 모드만 고려.

## 결과

| 반지름 | 높이 | 반경 차단 `0.61c/a` | 첫 반경 모드 `f(1,1)` | 대역 내 1D 모드 | **대역 내 추가 2D 모드** |
|---:|---:|---:|---:|---:|---:|
| 1 cm | 5 / 15 cm | 20,949 Hz | 대역 밖 | 2 / 5 | **0** |
| 2 cm | 5 / 15 cm | 10,474 Hz | 대역 밖 | 2 / 5 | **0** |
| 4 cm | 5 cm | 5,237 Hz | 5,361 Hz | 2 | **0** |
| 4 cm | 15 cm | 5,237 Hz | 5,259 Hz | 5 | **0** |

**최악 케이스 상세 (r=4cm, L=15cm):**
- 1D 축 모드 (대역 내): **492, 1476, 2460, 3443, 4427 Hz** — 2D의 `p=0` 모드와 **완전 동일**.
- 2D 첫 반경 모드: **5,259 Hz** — 측정 대역(5000 Hz) **바로 위**.

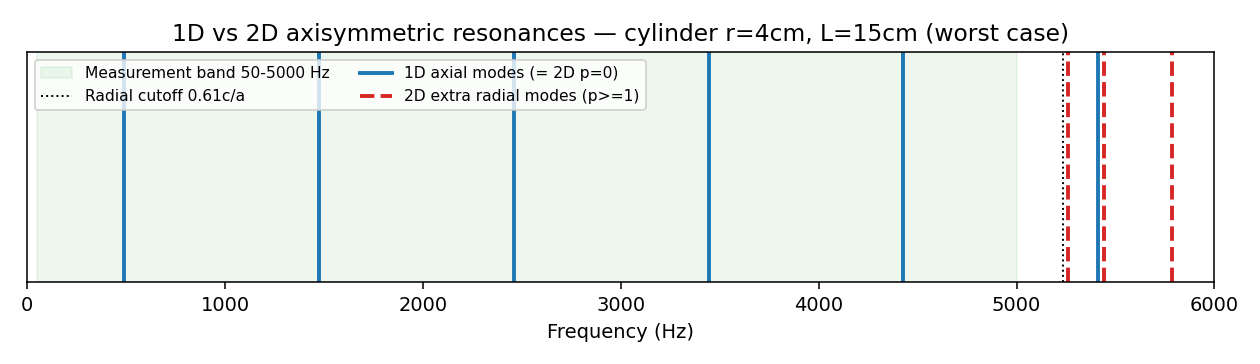
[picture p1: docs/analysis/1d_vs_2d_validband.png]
1D vs 2D


## 결론
- **50~5000 Hz 대역 안에는 2D가 추가하는 반경 모드가 하나도 없다** (r ≤ 4cm 전 범위).
- 따라서 **대역 내 공명 주파수는 1D = 2D (동일).** → **1D TMM 유지**가 타당(더 단순·빠르고 미분가능, PINN에 유리).
- 이전에 언급된 "2500 Hz 한계"는 각 모드 `(1,0)` 차단(`0.293c/a`) 기준이었으나, **on-axis 셋업에선 이 모드가 축상 마디라 가진·감지되지 않음** → 실질 한계는 첫 반경 모드 `≈ 0.61c/a ≈ 5,259 Hz`(넓은 컵)로, 대역이 그 아래에 있음.

## 한계 / 재검토 조건
- 본 비교는 **공명 주파수** 기준. 아래 2차 효과는 차단 아래라 작으며, 필요 시 멀티모달법으로 정밀화 가능:
  1. 링 **단차(step) 접합부**의 소멸(evanescent) 모드 보정 — 1D는 면적 연속으로 근사(주도항 정확).
  2. 입구 **방사**(마이크 B 모델의 외부장)는 내부 1D/2D 유효성과 무관한 별개 관측 모델.
- **재검토 트리거**: 측정 대역을 5 kHz 초과로 확장하거나, **비원형(사각 등) 단면** 실제 배관을 다룰 때 (후자는 각 모드 = 완전 3D 필요, on-axis에선 약함).

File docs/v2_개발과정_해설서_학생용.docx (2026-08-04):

소리로 컵의 내부 형상을 알아내다

음향-물채움 형상 역추적 연구: v2 파이프라인 개발 해설서

(과학고등학교 학생 연구팀용 상세 설명 자료)

2026년 7월 4일 기준

# 목차

(Word에서 열면 목차에서 마우스 오른쪽 → “필드 업데이트”를 눌러 페이지 번호를 채우세요.)

# 1. 이 연구가 풀려는 문제

불투명한 컵이나 병의 내부가 어떻게 생겼는지, 안을 들여다보지 않고 알아낼 수 있을까? 이 연구의 답은 “물을 부으면서 소리를 들으면 된다”이다. 컵 속 공기 기둥은 관악기처럼 고유한 공명 주파수를 가지는데, 물이 차오르면 공기 기둥이 짧아지면서 공명 주파수가 변한다. 이 변화의 궤적은 컵의 내부 형상에 따라 달라지므로, 거꾸로 소리의 궤적을 보고 형상을 추정할 수 있다.

## 1-1. 왜 어려운가: 역문제와 비유일성

형상을 알 때 소리를 계산하는 것을 순방향 문제라 하고, 소리에서 형상을 알아내는 것을 역문제(inverse problem)라 한다. 역문제가 어려운 이유는 “서로 다른 형상이 거의 같은 소리를 낼 수 있기” 때문이다. 이를 해의 비유일성(ill-posed)이라 한다. 소리 한 번만 들어서는 답이 하나로 정해지지 않는다.

이 연구의 핵심 아이디어는 물채움 자체를 해결 장치로 쓰는 것이다. 물이 차오를 때마다 공기 기둥의 바닥(수면) 위치가 바뀌므로, 사실상 서로 다른 조건에서 수십 번 측정하는 셈이 된다. 여러 조건의 측정을 모으면 답이 하나로 좁혀진다(유일성 복원).

## 1-2. 두 개의 정보 채널

- 음향 채널: 공명 주파수 → 공기 기둥 길이 → 수위 h(t)를 알려준다.
- 유체 채널(연속방정식): 부은 물의 양 V와 수위 변화를 결합하면 단면적 A(h) = ΔV/Δh 를 알 수 있다. 물이 바닥부터 꼭대기까지 모든 높이를 한 번씩 지나가므로, 이 관계만으로도 전체 단면적 분포를 복원할 수 있다.

즉 인공지능(딥러닝)은 이 두 물리 채널이 주는 정보를 결합하는 역할을 한다. 물리가 정보를 보증하고, AI가 그것을 읽어내는 구조다.

## 1-3. 최종 목표

시뮬레이션으로 만든 데이터로 AI를 학습시키고, 실제 마이크로 녹음한 소리로 형상을 추정하는 것(sim-to-real)이 본선 전략이다. 자동화 측정 장치(링 적층 리그)는 정답을 아는 형상으로 방법을 검증하고, 전람회장에서 전 과정을 자동 시연하는 역할을 한다.

# 2. 용어 사전

보고서를 쓸 때 아래 용어를 정확히 쓰는 것만으로 글의 신뢰도가 크게 올라간다.

## 2-1. 물리 용어

용어 | 뜻
기주공명 | 관 속 공기 기둥이 특정 주파수에서 크게 진동하는 현상. 병 입구에 바람을 불면 소리가 나는 원리
스펙트럼 | 소리를 주파수별 세기로 분해한 그래프. 이 연구의 기본 데이터 형태
전달함수 H(f) | 각 주파수의 소리가 시스템을 통과하며 몇 배가 되는지의 함수. 직렬 연결이면 서로 곱해진다
비율 전달함수 | 컵 있음 측정 ÷ 컵 없음 측정. 스피커·마이크·방의 특성이 약분되어 사라지고 컵의 효과만 남는다
딥(dip) | 스펙트럼에서 아래로 파인 골짜기. 우리 관측에서 공명은 피크가 아니라 딥으로 나타난다
관구보정(end correction) | 공명하는 공기 기둥이 입구 밖으로 약 0.8×반지름만큼 삐져나오는 효과. 실제로 존재하는 공기 덩어리다
감쇠(damping) | 관 벽 근처의 점성·열 손실로 공명이 무한히 날카로워지지 않고 유한한 폭을 갖게 되는 효과 (Kirchhoff 공식)
TMM(전달행렬법) | 관을 얇은 원판 조각으로 썰어, 각 조각의 소리 통과 규칙(2×2 행렬)을 차례로 곱해 전체 응답을 구하는 계산법

## 2-2. 딥러닝 용어

용어 | 뜻
피처(feature) | 모델에 들어가는 입력값. 우리는 주파수 500칸(빈)의 스펙트럼 + 부은 물의 양 V
레이블(label) | 모델이 맞혀야 할 정답. 우리는 높이 H와 10mm 간격 반지름 25개(슬롯)
샘플(sample) | 데이터 1개. 컵 하나의 (물채움 스펙트럼 시퀀스, 정답 형상) 쌍
에포크(epoch) | 전체 데이터셋을 처음부터 끝까지 한 바퀴 학습하는 단위
배치(batch) | 샘플을 묶어 한 번에 처리하는 단위 (예: 64개씩)
로스(loss) | 예측과 정답의 차이를 숫자 하나로 요약한 값. 학습 = 이 값을 줄이는 방향으로 가중치 조정
정규화 / 표준화 | 정규화: min-max로 [0,1] 범위로. 표준화(z-score): 평균 0, 표준편차 1로 맞춤
학습/검증/테스트 분할 | 데이터를 80/10/10으로 나눔. 학습용으로 배우고, 검증용으로 진행 상황을 감시하고, 테스트용(모델이 한 번도 못 본 것)으로 최종 채점
과적합(overfitting) | 학습 데이터는 잘 맞히지만 새 데이터에서 성능이 떨어지는 상태. 학습 로스는 내려가는데 검증 로스가 올라가면 신호
증강(augmentation) | 학습 데이터에 현실적인 변형(노이즈, 왜곡 등)을 가해 모델을 튼튼하게 만드는 기법
마스킹(masking) | 가변 길이 데이터에서 “어디까지가 진짜인지”를 0/1 표시로 알려주는 기법
하이퍼파라미터 | 모델이 배우는 값이 아니라 사람이 정해주는 설정값 (학습률, 에포크 수, 대역 폭 등)
정답 누설(label leakage) | 정답에서 파생된 정보가 입력에 섞이는 실수. 성적은 좋아 보이지만 실전에서 무너진다
보정(calibration) | 모델 출력의 눈금(스케일·원점)을 교정하는 것. 저울 영점 조절과 같은 원리

# 3. 전체 파이프라인 한눈에 보기

v2 시스템은 5단계의 조립 라인이다. 각 단계는 독립된 코드 파일이고, 앞 단계의 출력이 뒷 단계의 입력이 된다.

단계 | 하는 일 | 코드 파일
1. 순방향 시뮬레이터 | 형상 → 딥 스펙트럼 계산 (물리 엔진) | v2/forward/tmm.py
2. 데이터 생성기 | 무작위 형상 10만 개 × 물채움 시퀀스 생성 | v2/data/generate.py, shapes.py
3. 전처리·증강 로더 | 학습 직전 실시간으로 노이즈·왜곡 입히기 | v2/data/loader.py
4. 모델·학습 | 스펙트럼 시퀀스 → 형상 추정 신경망 학습 | v2/models/baseline.py, v2/train.py
5. 통합 앱 | 탐색·데이터검사·학습·추론을 한 화면에서 | v2/app.py (streamlit)

설계 원칙: 모든 물리 상수(반지름 범위, 주파수 대역, 정규화 기준 등)는 v2/config.py 한 곳에만 둔다. 데이터에서 계산한 값을 기준으로 쓰면 데이터를 다시 만들 때마다 기준이 흔들리는 사고가 나기 때문이다.

# 4. 1단계: 순방향 시뮬레이터 — 소리를 예측하는 물리 엔진

## 4-1. TMM: 관을 썰어서 곱한다

임의 형상의 컵은 반지름이 높이에 따라 변하는 관이다. 이를 5mm 두께의 얇은 원판 조각들로 썰면, 각 조각은 단면적이 일정한 짧은 원통이 된다. 소리가 원통 하나를 통과할 때 압력과 유량이 어떻게 변하는지는 2×2 행렬 하나로 정확히 표현되고, 조각들의 행렬을 차례로 곱하면 컵 전체의 응답이 나온다. 이것이 전달행렬법(TMM)이다. 바닥(또는 수면)은 소리를 완전히 반사하는 벽, 입구는 소리가 방사되는 열린 끝으로 처리한다.

## 4-2. 왜 피크가 아니라 딥을 재는가

마이크에 녹음되는 소리에는 스피커 특성 S, 방의 울림 R, 마이크 특성 M이 전부 곱해져 있다: 녹음 = 입력 × S × R × M × (컵 효과). 시뮬레이터가 계산할 수 있는 것은 컵 효과뿐이므로, S·R·M을 없애야 시뮬과 실측을 비교할 수 있다. 방법은 간단하다. 같은 세팅에서 “컵 있음”과 “컵 없음(평평한 강체판)”을 두 번 재서 나누면 S·R·M이 분자와 분모에서 약분된다. 이 비율 전달함수가 우리의 공식 관측량이고, 공명 주파수마다 깊은 딥이 파인 모양이 된다. 마이크를 입구 바로 위(10mm)에 두면 모든 공명 모드가 일관되게 딥으로 나타나는 것도 장점이다.

## 4-3. 감쇠: 무손실 시뮬레이션의 함정

손실이 전혀 없는 이상적 시뮬레이션에서는 공명이 무한히 날카로워서, 주파수를 700칸으로 나눠 기록할 때 칸 사이로 빠져 아예 안 보일 수 있다. 실제 공기에는 관 벽 근처의 점성·열 손실이 있어 딥이 유한한 폭과 깊이를 갖는다. 이 손실은 Kirchhoff의 고전 공식으로 상수까지 알려져 있어 튜닝할 값이 하나도 없다는 것이 중요하다. 물리 문헌값만으로 실측과 같은 모양의 딥이 만들어진다.

## 4-4. 검증, 그리고 뜻밖의 물리 발견

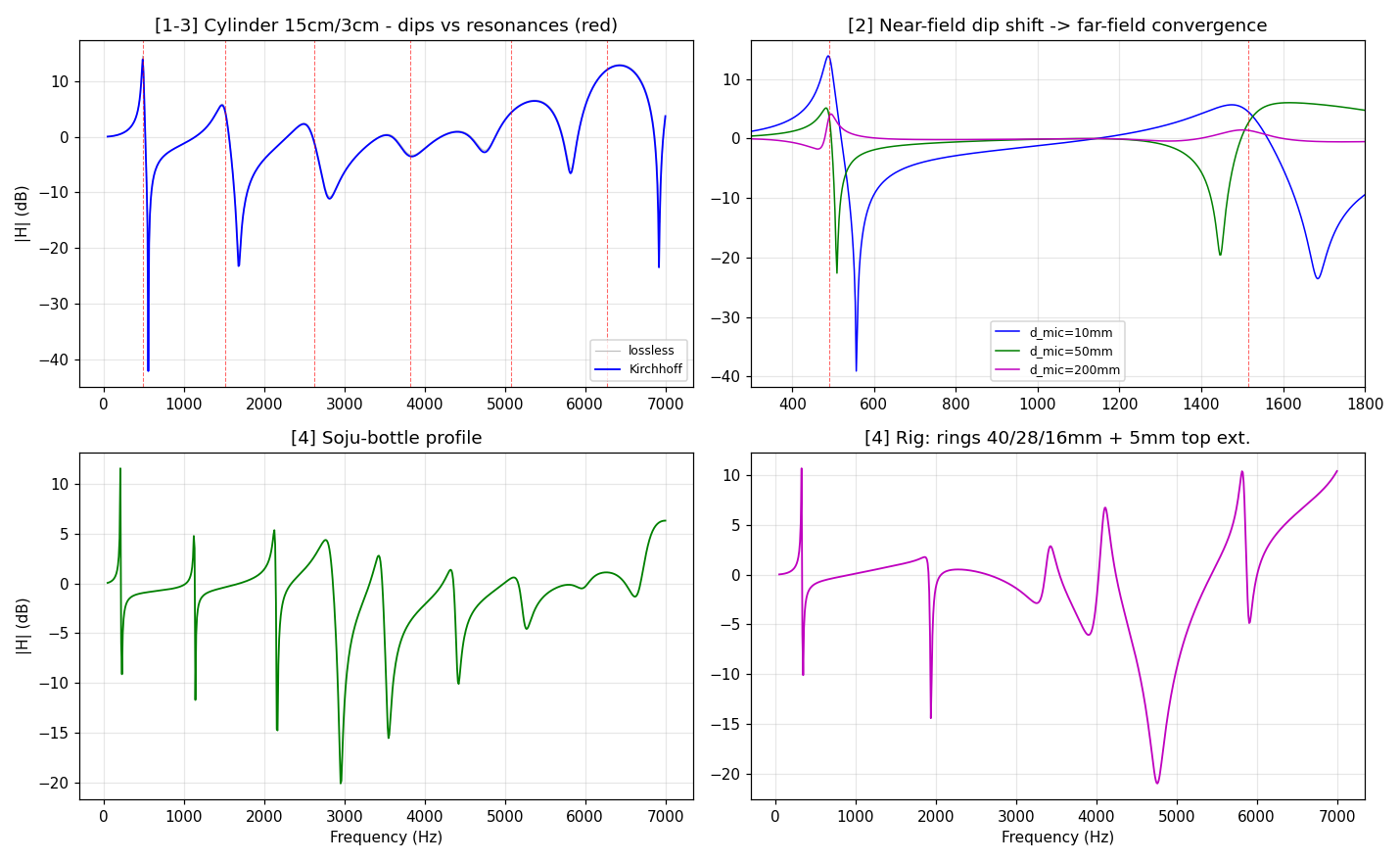
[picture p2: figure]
forward validation

그림 1. 순방향 시뮬레이터 검증. (좌상) 원통 컵의 딥 스펙트럼과 공명 위치(빨간 선), (우상) 마이크 높이에 따른 딥 위치 이동, (하단) 소주병·리그 계단 형상의 딥 스펙트럼

시뮬레이터는 두 단계로 검증했다. 첫째, 공명 주파수 위치를 교과서 해석해와 비교해 저차 모드에서 오차 3% 미만을 확인했다. 둘째 검증에서 처음에는 버그로 보이는 현상이 나타났다: 딥의 위치가 공명 주파수보다 14%나 높게 찍힌 것이다.

추적 결과 이것은 버그가 아니라 진짜 물리였다. 관구보정 때문에 공명 시 압력 마디(진동이 0이 되는 지점)는 입구 평면이 아니라 입구 위 약 25mm에 떠 있다. 마이크는 입구 위 10mm, 즉 공명기의 “가상 연장부” 안에 들어가 있어서, 고정된 마이크 위치를 마디가 지나가는 주파수(공명보다 높음)에서 최소 압력을 읽게 된다. 실제로 마이크를 10→30→60→100mm로 멀리 하면 딥이 557→524→504→494Hz로 공명(489Hz)에 수렴하는 것을 수치로 확인했다. 실제 마이크도 같은 위치에 있으므로 실측에서도 같은 이동이 나타날 것이며, 이는 오히려 모델을 실험으로 검증할 예측이 된다.

교훈: 시뮬레이션과 이론이 다르면 (1) 코드 버그, (2) 이론(비교 기준)의 한계, (3) 새로운 물리 세 가지 가능성을 모두 의심해야 한다. 이번 경우는 (2)와 (3)이 섞여 있었다.

# 5. 2단계: 데이터 프로토콜 — 물을 “어떻게” 부을 것인가

## 5-1. 확정된 규칙

- 한 번에 붓는 양: 고정 ΔV = 10mL (모든 컵 동일)
- 멈추는 기준: 남은 공기 기둥이 30mm가 되기 직전까지 (부피 %가 아니라 높이 기준 — 넘침 위험은 높이로 결정되므로)
- 형상 범위: 반지름 5~50mm, 높이 30~250mm 연속 무작위 (텀블러·소주병·맥주잔·와인잔 포함)
- 안전장치: 최소 채움 부피 40mL(최소 5회 측정 보장), 최대 128스텝 캡(초대형 컵의 시간 폭발 방지)

## 5-2. ΔV는 어떻게 정했나: 데이터로 결정

붓는 양이 작을수록 측정이 촘촘해지지만 시간이 오래 걸린다. 형상 2만 개를 미리 뽑아 후보(10/20/30/50mL)를 비교했다. 판단 기준은 “한 번 부을 때 수위가 얼마나 뛰는가”였다. 출력 해상도가 10mm 슬롯이므로, 유체 채널이 이를 받치려면 스텝당 수위 상승이 10mm보다 작아야 한다. 10mL만이 이 조건(중앙값 3.8mm)을 여유 있게 만족했다.

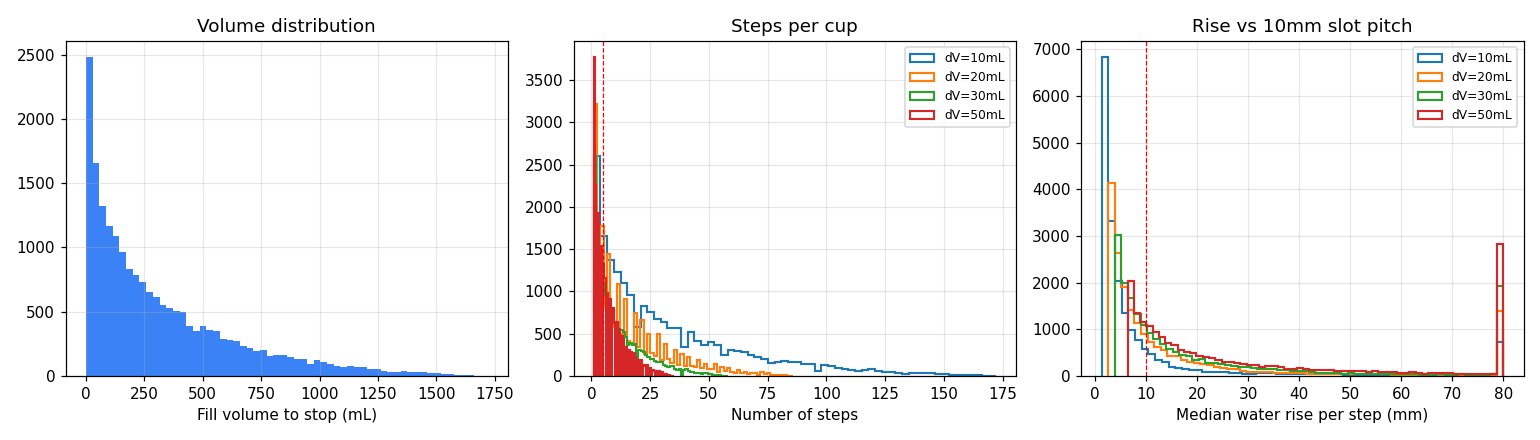
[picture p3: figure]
dV study

그림 2. ΔV 스터디. (좌) 컵별 채움 부피 분포, (중) ΔV별 스텝 수 분포, (우) 스텝당 수위 상승 vs 10mm 기준선

## 5-3. 기각된 아이디어들과 그 이유 (중요!)

좋아 보이지만 함정이 있는 아이디어들이 있었다. 왜 기각됐는지 이해하는 것이 이 연구의 핵심 논리 훈련이다.

- 컵 부피를 N등분해서 붓기: 등분하려면 컵 부피(=정답)를 미리 알아야 한다. 그 ΔV를 입력에 넣으면 모델이 “부피 = N×ΔV”라는 지름길을 배워버린다. 이것이 정답 누설이다. 학습 성적은 완벽해 보이지만, 정답을 모르는 실전에서는 무너진다.
- 지수 증분(10, 20, 40mL...): 누설은 없지만 마지막 붓기가 컵의 절반이 되어 위쪽 형상 정보가 뭉개진다.
- 올바른 개선안(v2 예정): 직전 붓기로 수위가 얼마나 올랐는지를 측정으로 추정해, 매번 수위가 약 8mm씩 오르도록 붓는 양을 조절하는 적응형 방식. 측정에 근거하므로 누설이 없고, 실전에서도 실행 가능하다.

# 6. 3단계: 전처리와 증강 — 현실을 흉내 내는 기술

## 6-1. 전처리: 모델이 먹기 좋게 다듬기

- 스펙트럼: log를 취한 뒤 시퀀스 전체 단위로 z-score 표준화. 녹음 게인(볼륨)은 곱셈이라 log에서 덧셈 상수가 되고, 평균을 빼는 순간 정확히 사라진다. 스텝마다 따로 표준화하면 스텝 사이의 진폭 관계(물리 신호)까지 지워지므로 금지.
- 부은 부피 V: 1L라는 고정 상수로 나눈다. “그 컵의 최대 부피”로 나누면 절대 크기 정보가 사라지므로 금지.
- 정답: 장치 설계로 정해진 물리 상수(반지름 5~50mm, 높이 30~250mm)로 min-max 정규화.
- 가변 길이: 컵마다 스텝 수가 다르므로(5~129개) 빈자리를 0으로 채우고(패딩), 어디까지 진짜인지 0/1 마스크로 알려준다. 채점(로스)도 물이 닿은 유효 슬롯에서만 한다.

## 6-2. 증강: 왜 깨끗한 데이터를 일부러 더럽히는가

시뮬레이션은 깨끗하지만 실제 녹음은 지저분하다. 이 간극(sim-to-real gap)을 줄이기 위해, 학습 중 매 샘플마다 실시간으로 현실적인 오염을 입힌다. 미리 데이터에 구워 넣지 않고 로더에서 실시간으로 하기 때문에, 같은 컵이 에포크마다 조금씩 다른 모습으로 나타나 모델이 오염의 패턴이 아닌 물리의 패턴을 배우게 된다.

증강 | 흉내 내는 현실 | 적용 방법
시그니처 곱하기 | 스피커·마이크·방의 주파수 특성 | log 스펙트럼에 완만한 곡선 더하기
소음 바닥 더하기 | 배경 소음 때문에 딥이 끝까지 안 파임 | 선형 파워 영역에서 노이즈와 합성
온도 변화(15~30°C) | 음속 변화로 공명 위치 이동 | 주파수 축을 0.98~1.02배 늘였다 줄임
마이크 높이 ±1mm | 지그 조립 오차 | 주파수 미세 이동
가짜 딥(4~7kHz) | 1D 모델이 계산 못 하는 반경 방향 공명 | 무작위 위치에 딥 심기 → 모델이 그 대역을 과신하지 않게 됨
스텝 서브샘플링 | 적응형 프로토콜의 가변 간격 붓기 | 저장된 시퀀스에서 일부 스텝만 무작위 발췌

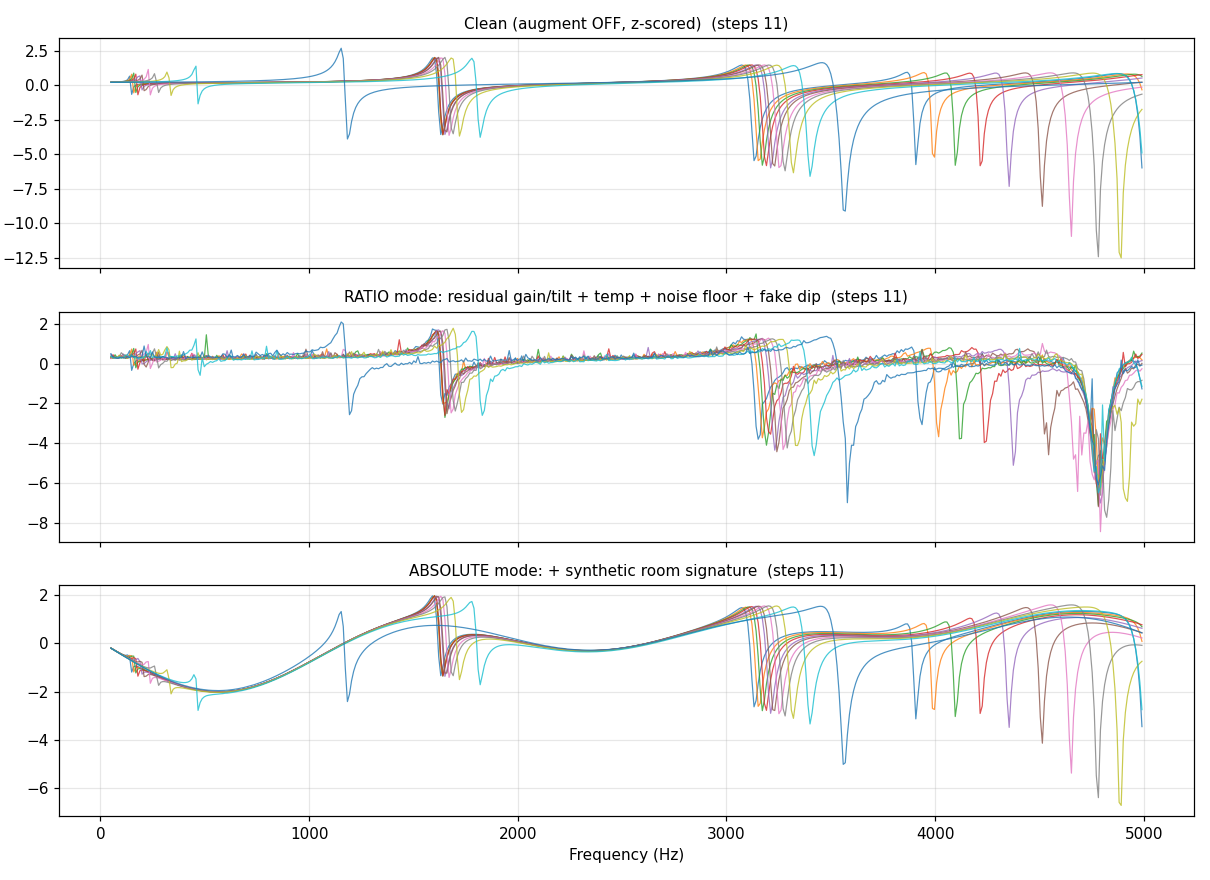
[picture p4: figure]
augmentation

그림 3. 같은 컵의 세 가지 모습. (상) 깨끗한 시뮬, (중) ratio 모드 증강 — 소음 바닥과 가짜 딥, (하) absolute 모드 — 합성 룸 시그니처가 곱해진 모습

증강에는 두 모드가 있다. ratio 모드는 비율 전달함수 관측(기기 특성이 약분된 후의 잔여 오염만), absolute 모드는 절대 스펙트럼 관측(시그니처를 통째로 곱함)에 대응한다. 전람회 전날 전시장에서 시그니처를 녹음해 absolute 모드로 미세조정하는 것이 주 전략이고, ratio 모드 모델은 재학습이 필요 없는 안전망이다.

# 7. 4단계: 모델과 학습

## 7-1. 모델 구조 (베이스라인 CNN)

모델은 세 부분으로 이루어진다. (1) 스텝 인코더: 각 스텝의 스펙트럼(498칸)을 1차원 CNN이 훑어 256개의 특징으로 요약한다. CNN은 작은 필터를 옆으로 밀며 딥의 위치·간격·깊이 같은 국소 패턴을 감지하는 층이다. (2) 부피 임베딩: 각 스텝의 V값을 작은 신경망으로 32개 특징으로 바꿔 스펙트럼 특징과 합친다. (3) 풀링과 머리: 모든 스텝의 특징을 평균·최대값으로 합치고(마스크로 패딩 제외), 두 갈래 출력으로 높이 H(1개)와 반지름 슬롯(25개)을 내놓는다.

이 모델은 일부러 스텝의 순서를 무시하고 합친다(집합 방식). 다음 단계에서 순서를 기억하는 RNN과 비교하면 “물채움의 시간 순서 정보가 얼마나 기여하는가”를 실험으로 분리해 보여줄 수 있기 때문이다. 이렇게 조건을 하나씩 바꿔 기여도를 재는 실험을 어블레이션(ablation)이라 한다.

## 7-2. 로스와 평가 지표

로스 = 슬롯 오차(유효 슬롯만 MSE) + 3×높이 오차(MSE). 사람이 읽는 지표로는 정규화를 되돌린 mm 단위 평균 절대 오차(H_MAE, r_MAE)를 쓴다. 데이터 10만 개는 학습 8만 / 검증 1만 / 테스트 1만으로 나누고, 매 에포크 끝에 검증 성적을 재서 최고 기록일 때의 가중치를 저장한다(베스트 체크포인트). 테스트 1만 개는 학습 과정에서 한 번도 쓰지 않고 최종 채점에만 쓴다.

# 8. 5단계: 진단 이야기 — “예측이 80mm로 끌려간 사건”

첫 본학습(10만 샘플, 30에포크) 후 테스트에서 이상한 패턴이 발견됐다. 높이 80mm짜리 컵은 잘 맞히는데, 그보다 큰 컵은 작게, 작은 컵은 크게 추정하는 것이다. 오차가 (h−80)에 비례하는 모양이었다. 코딩 버그인가, 아니면 방법의 본질적 한계인가?

## 8-1. 실험으로 판별하기

테스트 컵 200개에 대해 (실제 높이, 예측 높이)를 산점도로 그렸다(그림 4 왼쪽). 점들은 흩어진 구름이 아니라 거의 완벽한 직선을 이뤘다(상관계수 0.9977). 다만 그 직선이 “예측=실제” 대각선이 아니라 기울기 0.84로 눕혀져 있었다: 예측 = 0.84×h + 10. 이 직선과 대각선이 만나는 지점이 약 70mm — 관찰된 “80으로 끌려감”의 정체다.

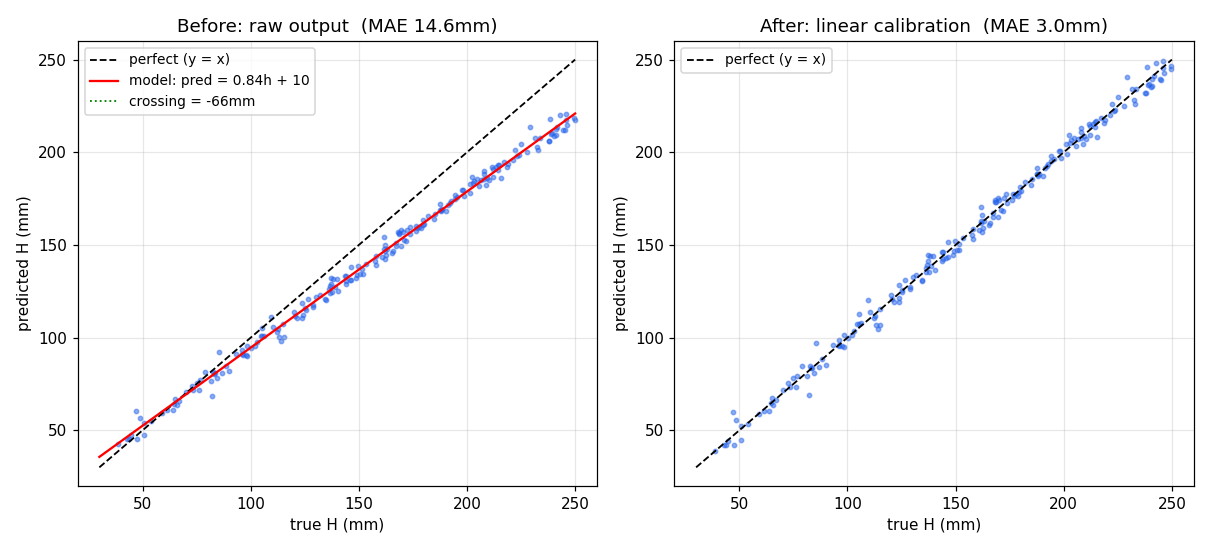
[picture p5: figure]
calibration

그림 4. (좌) 보정 전: 점들이 기울기 0.84의 직선 위에 — 정보는 완벽하나 눈금이 압축됨. (우) 1차 보정 후: 오차 14.6mm → 3.0mm

이 그림이 판결문이다. 만약 본질적 한계(정보 부족)라면 점들이 구름처럼 흩어졌을 것이다. 점들이 팽팽한 직선이라는 것은 모델이 컵들의 높이 순서와 간격을 완벽히 알고 있고, 단지 출력의 눈금(스케일)이 84%로 압축된 채 멈췄다는 뜻이다. 실제로 직선을 도로 세우는 1차 보정(1.18배 늘리고 11.6 빼기)만으로 오차가 14.6mm에서 3.0mm로 떨어졌다. 84% 크기로 인쇄된 자로 잰 값들을 1.18배 해주는 것과 같은, 계측기 교정과 동일한 표준 절차다.

## 8-2. 왜 눈금이 덜 펴졌나: 두 과제의 시소

학습 로그의 검증 로스를 높이 성분과 슬롯 성분으로 분리해 보니, 두 성분이 시소를 타고 있었다. 슬롯이 좋아지는 에포크에는 높이가 나빠지고, 그 반대도 일어났다. 두 출력이 하나의 몸통(공유 특징망)을 서로 자기 쪽으로 당기는 멀티태스크 간섭이다. 베스트 저장 기준이 두 성분의 합이었기 때문에, 높이 눈금이 다 펴지기 전의 순간이 베스트로 동결됐다.

처방: (1) 학습률을 절반으로 낮추고 후반에 더 줄이는 스케줄 적용(진동 감소), (2) weight decay로 과적합 억제, (3) 높이 단독 베스트 체크포인트를 별도 저장, (4) 학습 종료 시 검증셋으로 보정 계수를 자동 적합해 체크포인트에 내장. 이 처방의 효과는 다음 학습 로그로 검증한다.

교훈: 딥러닝 디버깅은 “관찰 → 가설 → 실험 → 판정”의 과학적 방법 그 자체다. “오차가 (h−80)에 비례한다”는 정량적 관찰이 있었기에 원인을 특정할 수 있었다. 보고서에는 이 과정 자체를 실험 서사로 쓸 수 있다.

# 9. 현재 성과와 남은 일

## 9-1. 지금까지 확인된 성능 (시뮬레이션 기준)

- 높이 H: 보정 후 평균 오차 약 3mm (참고: 선행연구인 옥스퍼드 2025는 원통 가정에 높이 오차 22mm 수준)
- 반지름 슬롯: 평균 오차 약 2mm — 원통 하나가 아니라 10mm 간격의 내부 프로파일 전체를 복원
- 단, 이는 시뮬레이션 안에서의 성적이다. 실측(sim-to-real)에서의 성능이 이 연구의 진짜 시험대다.

## 9-2. 로드맵

- 모델 사다리: 베이스라인 CNN(순서 무시) → RNN(순서 기억) → PINN(물리 법칙을 로스에 내장). 단계별 성능 향상 자체가 각 아이디어의 기여 증거가 된다.
- 실측 파이프라인: 스윕 신호 디컨볼루션으로 전달함수 추출 → 링 리그로 정답 아는 형상 검증 → 마이크 높이 스윕으로 근접장 이동 예측(557→494Hz) 실증
- 전람회 시연: 전날 전시장 시그니처 녹음 → 밤새 미세조정 → 당일 자동 측정·실시간 추정

# 10. 보고서 작성을 위한 팁

- “무엇을 했다”보다 “왜 그렇게 했다”를 써라. 이 문서의 5-3절(기각된 아이디어), 8장(진단 이야기)이 좋은 재료다. 심사위원의 질문은 대부분 “왜”에서 나온다.
- 그림 1(물리 검증), 그림 2(설계 결정), 그림 4(진단과 보정)는 각각 “검증-설계-분석”의 증거로 인용할 수 있다.
- 용어를 정확히: 정규화와 표준화 구분, 검증셋과 테스트셋 구분, “정확도” 대신 “평균 절대 오차(MAE, mm)”.
- 한계를 스스로 말하라: 현재 성능은 시뮬레이션 기준이며, 실측 검증은 진행 중이라는 것. 한계를 아는 것이 연구의 신뢰도를 만든다.
- 재현 정보: 데이터 10만 샘플, 학습/검증/테스트 = 8/1/1, 베이스라인 CNN 약 80만 파라미터, 입력은 스텝별 498빈 스펙트럼 + 부은 부피, 출력은 높이 + 25슬롯 반지름.

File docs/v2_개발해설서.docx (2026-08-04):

소리로 컵의 내부 형상을 알아내다

음향-물채움 형상 역추적 연구: v2 파이프라인 개발 해설서

(과학고등학교 학생 연구팀용 상세 설명 자료)

2026년 7월 5일 기준

# 목차

(Word에서 열면 목차에서 마우스 오른쪽 → “필드 업데이트”를 눌러 페이지 번호를 채우세요.)

# 1. 이 연구가 풀려는 문제

불투명한 컵이나 병의 내부가 어떻게 생겼는지, 안을 들여다보지 않고 알아낼 수 있을까? 이 연구의 답은 “물을 부으면서 소리를 들으면 된다”이다. 컵 속 공기 기둥은 관악기처럼 고유한 공명 주파수를 가지는데, 물이 차오르면 공기 기둥이 짧아지면서 공명 주파수가 변한다. 이 변화의 궤적은 컵의 내부 형상에 따라 달라지므로, 거꾸로 소리의 궤적을 보고 형상을 추정할 수 있다.

## 1-1. 왜 어려운가: 역문제와 비유일성

형상을 알 때 소리를 계산하는 것을 순방향 문제라 하고, 소리에서 형상을 알아내는 것을 역문제(inverse problem)라 한다. 역문제가 어려운 이유는 “서로 다른 형상이 거의 같은 소리를 낼 수 있기” 때문이다. 이를 해의 비유일성(ill-posed)이라 한다. 소리 한 번만 들어서는 답이 하나로 정해지지 않는다.

이 연구의 핵심 아이디어는 물채움 자체를 해결 장치로 쓰는 것이다. 물이 차오를 때마다 공기 기둥의 바닥(수면) 위치가 바뀌므로, 사실상 서로 다른 조건에서 수십 번 측정하는 셈이 된다. 여러 조건의 측정을 모으면 답이 하나로 좁혀진다(유일성 복원).

## 1-2. 두 개의 정보 채널

- 음향 채널: 공명 주파수 → 공기 기둥 길이 → 수위 h(t)를 알려준다.
- 유체 채널(연속방정식): 부은 물의 양 V와 수위 변화를 결합하면 단면적 A(h) = ΔV/Δh 를 알 수 있다. 물이 바닥부터 꼭대기까지 모든 높이를 한 번씩 지나가므로, 이 관계만으로도 전체 단면적 분포를 복원할 수 있다.

즉 인공지능(딥러닝)은 이 두 물리 채널이 주는 정보를 결합하는 역할을 한다. 물리가 정보를 보증하고, AI가 그것을 읽어내는 구조다.

## 1-3. 최종 목표

시뮬레이션으로 만든 데이터로 AI를 학습시키고, 실제 마이크로 녹음한 소리로 형상을 추정하는 것(sim-to-real)이 본선 전략이다. 자동화 측정 장치(링 적층 리그)는 정답을 아는 형상으로 방법을 검증하고, 전람회장에서 전 과정을 자동 시연하는 역할을 한다.

# 2. 용어 사전

보고서를 쓸 때 아래 용어를 정확히 쓰는 것만으로 글의 신뢰도가 크게 올라간다.

## 2-1. 물리 용어

용어 | 뜻
기주공명 | 관 속 공기 기둥이 특정 주파수에서 크게 진동하는 현상. 병 입구에 바람을 불면 소리가 나는 원리
스펙트럼 | 소리를 주파수별 세기로 분해한 그래프. 이 연구의 기본 데이터 형태
전달함수 H(f) | 각 주파수의 소리가 시스템을 통과하며 몇 배가 되는지의 함수. 직렬 연결이면 서로 곱해진다
비율 전달함수 | 컵 있음 측정 ÷ 컵 없음 측정. 스피커·마이크·방의 특성이 약분되어 사라지고 컵의 효과만 남는다
딥(dip) | 스펙트럼에서 아래로 파인 골짜기. 우리 관측에서 공명은 피크가 아니라 딥으로 나타난다
관구보정(end correction) | 공명하는 공기 기둥이 입구 밖으로 약 0.8×반지름만큼 삐져나오는 효과. 실제로 존재하는 공기 덩어리다
감쇠(damping) | 관 벽 근처의 점성·열 손실로 공명이 무한히 날카로워지지 않고 유한한 폭을 갖게 되는 효과 (Kirchhoff 공식)
TMM(전달행렬법) | 관을 얇은 원판 조각으로 썰어, 각 조각의 소리 통과 규칙(2×2 행렬)을 차례로 곱해 전체 응답을 구하는 계산법

## 2-2. 딥러닝 용어

용어 | 뜻
피처(feature) | 모델에 들어가는 입력값. 우리는 스텝별 스펙트럼(주파수 498칸) + 부은 물의 양 V
레이블(label) | 모델이 맞혀야 할 정답. 우리는 높이 H와 10mm 간격 반지름 25개(슬롯)
샘플(sample) | 데이터 1개 = 컵 하나의 (물채움 스펙트럼 시퀀스, 정답 형상) 묶음
에포크(epoch) | 전체 데이터셋을 처음부터 끝까지 한 바퀴 도는 것
배치(batch) | 한 번에 묶어 처리하는 샘플 묶음 (예: 64개)
로스(loss) | 예측과 정답의 차이를 숫자 하나로 만든 오차 점수. 학습 = 이걸 줄이는 과정
학습률(learning rate) | 가중치를 고치는 보폭. 크면 빠르지만 거칠고, 작으면 정밀하지만 느림
정규화(normalization) | 값들을 0~1 같은 비슷한 크기로 맞추는 것(min-max). 우리는 데이터 통계가 아니라 물리 상수 기준으로 고정
z-score 표준화 | 평균을 빼고 표준편차로 나눠 평균 0·폭 1로 맞추는 것. 녹음 볼륨(게인) 차이를 지워준다
학습/검증/테스트 분할 | 데이터를 8:1:1로 나눔. 학습=공부, 검증=모의고사(베스트 선택), 테스트=수능(마지막에 한 번만)
과적합(overfitting) | 공부한 문제만 잘 풀고 새 문제를 못 푸는 상태. 학습 로스는 내려가는데 검증 로스가 올라가면 신호
증강(augmentation) | 데이터에 현실적인 변형·오염을 입혀 불려주는 것
하이퍼파라미터 | 모델이 배우는 값이 아니라 사람이 정해주는 설정값 (학습률, 에포크 수, 대역 폭 등)
체크포인트(checkpoint) | 학습된 가중치를 저장한 파일(.pt)
마스킹(masking) | 컵마다 길이가 다른 데이터에서 "여기까지가 진짜"라고 표시하는 0/1 배열
정답 누설(label leakage) | 정답에서 파생된 정보가 입력에 섞이는 실수. 성적은 좋아 보이지만 실전에서 무너진다
보정(calibration) | 모델 출력의 눈금(스케일·원점)을 검증 데이터로 교정하는 후처리. 저울 영점 조절·계측기 교정과 같은 원리

# 3. 전체 파이프라인 한눈에 보기

v2 시스템은 5단계의 조립 라인이다. 각 단계는 독립된 코드 파일이고, 앞 단계의 출력이 뒷 단계의 입력이 된다.

단계 | 하는 일 | 코드 파일
1. 순방향 시뮬레이터 | 형상 → 딥 스펙트럼 계산 (물리 엔진) | v2/forward/tmm.py
2. 데이터 생성기 | 무작위 형상 10만 개 × 물채움 시퀀스 생성 | v2/data/generate.py, shapes.py
3. 전처리·증강 로더 | 학습 직전 실시간으로 노이즈·왜곡 입히기 | v2/data/loader.py
4. 모델·학습 | 스펙트럼 시퀀스 → 형상 추정 신경망 학습 | v2/models/baseline.py, v2/train.py
5. 통합 앱 | 탐색·데이터검사·학습·추론을 한 화면에서 | v2/app.py (streamlit)

설계 원칙: 모든 물리 상수(반지름 범위, 주파수 대역, 정규화 기준 등)는 v2/config.py 한 곳에만 둔다. 데이터에서 계산한 값을 기준으로 쓰면 데이터를 다시 만들 때마다 기준이 흔들리는 사고가 나기 때문이다.

## 3-1. 파일별 역할

코드를 열기 전에 아래 지도를 먼저 보라. 파일 하나가 조립 라인의 한 정거장이다.

파일 | 역할
v2/config.py | 모든 물리 상수의 단일 출처. 범위·주파수·정규화 기준이 전부 여기 (다른 곳에 숫자 박지 말 것!)
v2/forward/tmm.py | 물리 엔진: 형상 → 딥 스펙트럼. 전달행렬법(TMM) + 벽 손실 + 마이크 관측 모델
v2/forward/validate_forward.py | 물리 엔진이 맞는지 검사. python으로 실행하면 PASS/FAIL이 나옴
v2/data/shapes.py | 무작위 컵 형상 생성 + 25슬롯 정답 라벨 계산
v2/data/generate.py | 학습 데이터 공장. 워커 여러 개로 병렬 실행
v2/data/loader.py | 전처리 + 증강. 학습 중 실시간으로 오염을 입힘
v2/models/baseline.py | 1호 신경망(CNN 계열). 스텝 순서를 무시하는 구조 — RNN과 비교하는 기준점
v2/train.py | 학습 실행기. 에폭별 성분 로그 CSV 저장, 베스트 저장, 자동 보정 내장
v2/app.py | 통합 앱(Streamlit). 탭 4개: 순방향 탐색 / 데이터셋 검사 / 학습 / 추정
v2/validation/ | 검증 그림들. 보고서에 그대로 쓸 수 있음
docs/연구_설계_프레임_v1.md | 설계의 헌법. 모든 결정과 그 이유
docs/RNN_설계_초안_v1.md | 다음 단계(RNN)의 설계 초안. 시소 대응(gradient 분리)이 내장되어 있다

## 3-2. 설계에서 지키는 규칙 (왜 이렇게 만들었나)

- 상수는 config.py 한 곳에만. 정규화 기준을 데이터에서 뽑으면 데이터셋을 다시 만들 때마다 기준이 흔들려 모델과 어긋난다. 물리 상수로 고정한다.
- 정답에서 파생된 값을 입력에 넣지 않는다. 예: 수위, 컵 부피로 계산한 ΔV. 이런 걸 넣으면 모델이 소리 대신 그 지름길만 배우고(정답 누설), 실전에서 무너진다. 부은 부피 V는 측정값이므로 괜찮다.
- 컵마다 길이가 달라도 패딩+마스크로 처리. 짧은 컵을 0으로 때우는 게 아니라 '여기까지 유효'를 명시한다.
- 증강은 저장하지 않고 학습 중 실시간으로. 시그니처 파일만 바꾸면 재학습 준비 끝 — 전람회 전날 현장 적응이 가벼워진다.
- 평가는 마지막까지 아껴둔 테스트 데이터로만. 검증셋으로 베스트를 고르고, 테스트셋은 최종 성적표에만 쓴다.

## 3-3. 따라하기: 명령어와 앱 사용법

데이터 만들기 (CPU, 터미널 여러 개 병렬)

python v2/data/generate.py --samples 12500 --worker_id 1

python v2/data/generate.py --samples 12500 --worker_id 2 # worker_id만 바꿔 코어 수만큼

워커 8개면 10만 샘플에 약 20~40분.

학습 (GPU)

python v2/train.py --smoke # 30초 동작 확인 (항상 먼저!)

python v2/train.py --mode ratio --epochs 30 --name base_ratio_v3

로그 읽는 법: val (r … h …) = 검증 로스의 슬롯/높이 성분. H_MAE·r_MAE = mm 단위 오차. 저장물: dataset/models_v2/이름.pt(베스트), 이름_bestH.pt(높이 단독 베스트), 이름_trainlog.csv(에폭별 성분 로그 — 시소 판정의 공식 근거).

앱 실행

streamlit run v2/app.py

- 1번 탭(순방향 탐색기): 사이드바에서 컵 모양을 만들면 딥 스펙트럼과 물채움 워터폴을 실시간으로 보여준다. '이 모양이면 이런 소리'라는 감을 잡는 곳.
- 2번 탭(데이터셋): 만들어진 데이터의 통계와 샘플 하나하나를 들여다본다.
- 3번 탭(학습): 명령어 대신 버튼으로 학습. 진행바와 로스 곡선(성분 포함)이 실시간으로 그려진다.
- 4번 탭(추정): 모델을 골라 테스트셋에서 무작위 추정(정답 vs 예측 겹쳐 그리기 + 스펙트로그램), 또는 사이드바에서 만든 형상을 즉석 추정한다.

# 4. 1단계: 순방향 시뮬레이터 — 소리를 예측하는 물리 엔진

## 4-1. TMM: 관을 썰어서 곱한다

임의 형상의 컵은 반지름이 높이에 따라 변하는 관이다. 이를 5mm 두께의 얇은 원판 조각들로 썰면, 각 조각은 단면적이 일정한 짧은 원통이 된다. 소리가 원통 하나를 통과할 때 압력과 유량이 어떻게 변하는지는 2×2 행렬 하나로 정확히 표현되고, 조각들의 행렬을 차례로 곱하면 컵 전체의 응답이 나온다. 이것이 전달행렬법(TMM)이다. 바닥(또는 수면)은 소리를 완전히 반사하는 벽, 입구는 소리가 방사되는 열린 끝으로 처리한다.

## 4-2. 왜 피크가 아니라 딥을 재는가

마이크에 녹음되는 소리에는 스피커 특성 S, 방의 울림 R, 마이크 특성 M이 전부 곱해져 있다: 녹음 = 입력 × S × R × M × (컵 효과). 시뮬레이터가 계산할 수 있는 것은 컵 효과뿐이므로, S·R·M을 없애야 시뮬과 실측을 비교할 수 있다. 방법은 간단하다. 같은 세팅에서 “컵 있음”과 “컵 없음(평평한 강체판)”을 두 번 재서 나누면 S·R·M이 분자와 분모에서 약분된다. 이 비율 전달함수가 우리의 공식 관측량이고, 공명 주파수마다 깊은 딥이 파인 모양이 된다. 마이크를 입구 바로 위(10mm)에 두면 모든 공명 모드가 일관되게 딥으로 나타나는 것도 장점이다.

## 4-3. 감쇠: 무손실 시뮬레이션의 함정

손실이 전혀 없는 이상적 시뮬레이션에서는 공명이 무한히 날카로워서, 주파수를 700칸으로 나눠 기록할 때 칸 사이로 빠져 아예 안 보일 수 있다. 실제 공기에는 관 벽 근처의 점성·열 손실이 있어 딥이 유한한 폭과 깊이를 갖는다. 이 손실은 Kirchhoff의 고전 공식으로 상수까지 알려져 있어 튜닝할 값이 하나도 없다는 것이 중요하다. 물리 문헌값만으로 실측과 같은 모양의 딥이 만들어진다.

## 4-4. 검증, 그리고 뜻밖의 물리 발견

forward validation

그림 1. 순방향 시뮬레이터 검증. (좌상) 원통 컵의 딥 스펙트럼과 공명 위치(빨간 선), (우상) 마이크 높이에 따른 딥 위치 이동, (하단) 소주병·리그 계단 형상의 딥 스펙트럼

시뮬레이터는 두 단계로 검증했다. 첫째, 공명 주파수 위치를 교과서 해석해와 비교해 저차 모드에서 오차 3% 미만을 확인했다. 둘째 검증에서 처음에는 버그로 보이는 현상이 나타났다: 딥의 위치가 공명 주파수보다 14%나 높게 찍힌 것이다.

추적 결과 이것은 버그가 아니라 진짜 물리였다. 관구보정 때문에 공명 시 압력 마디(진동이 0이 되는 지점)는 입구 평면이 아니라 입구 위 약 25mm에 떠 있다. 마이크는 입구 위 10mm, 즉 공명기의 “가상 연장부” 안에 들어가 있어서, 고정된 마이크 위치를 마디가 지나가는 주파수(공명보다 높음)에서 최소 압력을 읽게 된다. 실제로 마이크를 10→30→60→100mm로 멀리 하면 딥이 557→524→504→494Hz로 공명(489Hz)에 수렴하는 것을 수치로 확인했다. 실제 마이크도 같은 위치에 있으므로 실측에서도 같은 이동이 나타날 것이며, 이는 오히려 모델을 실험으로 검증할 예측이 된다.

교훈: 시뮬레이션과 이론이 다르면 (1) 코드 버그, (2) 이론(비교 기준)의 한계, (3) 새로운 물리 세 가지 가능성을 모두 의심해야 한다. 이번 경우는 (2)와 (3)이 섞여 있었다.

# 5. 2단계: 데이터 프로토콜 — 물을 “어떻게” 부을 것인가

## 5-1. 확정된 규칙

- 한 번에 붓는 양: 고정 ΔV = 10mL (모든 컵 동일)
- 멈추는 기준: 남은 공기 기둥이 30mm가 되기 직전까지 (부피 %가 아니라 높이 기준 — 넘침 위험은 높이로 결정되므로)
- 형상 범위: 반지름 5~50mm, 높이 30~250mm 연속 무작위 (텀블러·소주병·맥주잔·와인잔 포함)
- 안전장치: 최소 채움 부피 40mL(최소 5회 측정 보장), 최대 128스텝 캡(초대형 컵의 시간 폭발 방지)

## 5-2. ΔV는 어떻게 정했나: 데이터로 결정

붓는 양이 작을수록 측정이 촘촘해지지만 시간이 오래 걸린다. 형상 2만 개를 미리 뽑아 후보(10/20/30/50mL)를 비교했다. 판단 기준은 “한 번 부을 때 수위가 얼마나 뛰는가”였다. 출력 해상도가 10mm 슬롯이므로, 유체 채널이 이를 받치려면 스텝당 수위 상승이 10mm보다 작아야 한다. 10mL만이 이 조건(중앙값 3.8mm)을 여유 있게 만족했다.

dV study

그림 2. ΔV 스터디. (좌) 컵별 채움 부피 분포, (중) ΔV별 스텝 수 분포, (우) 스텝당 수위 상승 vs 10mm 기준선

## 5-3. 기각된 아이디어들과 그 이유 (중요!)

좋아 보이지만 함정이 있는 아이디어들이 있었다. 왜 기각됐는지 이해하는 것이 이 연구의 핵심 논리 훈련이다.

- 컵 부피를 N등분해서 붓기: 등분하려면 컵 부피(=정답)를 미리 알아야 한다. 그 ΔV를 입력에 넣으면 모델이 “부피 = N×ΔV”라는 지름길을 배워버린다. 이것이 정답 누설이다. 학습 성적은 완벽해 보이지만, 정답을 모르는 실전에서는 무너진다.
- 지수 증분(10, 20, 40mL...): 누설은 없지만 마지막 붓기가 컵의 절반이 되어 위쪽 형상 정보가 뭉개진다.
- 올바른 개선안(v2 예정): 직전 붓기로 수위가 얼마나 올랐는지를 측정으로 추정해, 매번 수위가 약 8mm씩 오르도록 붓는 양을 조절하는 적응형 방식. 측정에 근거하므로 누설이 없고, 실전에서도 실행 가능하다.

# 6. 3단계: 전처리와 증강 — 현실을 흉내 내는 기술

## 6-1. 전처리: 모델이 먹기 좋게 다듬기

- 스펙트럼: log를 취한 뒤 시퀀스 전체 단위로 z-score 표준화. 녹음 게인(볼륨)은 곱셈이라 log에서 덧셈 상수가 되고, 평균을 빼는 순간 정확히 사라진다. 스텝마다 따로 표준화하면 스텝 사이의 진폭 관계(물리 신호)까지 지워지므로 금지.
- 부은 부피 V: 1L라는 고정 상수로 나눈다. “그 컵의 최대 부피”로 나누면 절대 크기 정보가 사라지므로 금지.
- 정답: 장치 설계로 정해진 물리 상수(반지름 5~50mm, 높이 30~250mm)로 min-max 정규화.
- 가변 길이: 컵마다 스텝 수가 다르므로(5~129개) 빈자리를 0으로 채우고(패딩), 어디까지 진짜인지 0/1 마스크로 알려준다. 채점(로스)도 물이 닿은 유효 슬롯에서만 한다.

## 6-2. 증강: 왜 깨끗한 데이터를 일부러 더럽히는가

시뮬레이션은 깨끗하지만 실제 녹음은 지저분하다. 이 간극(sim-to-real gap)을 줄이기 위해, 학습 중 매 샘플마다 실시간으로 현실적인 오염을 입힌다. 미리 데이터에 구워 넣지 않고 로더에서 실시간으로 하기 때문에, 같은 컵이 에포크마다 조금씩 다른 모습으로 나타나 모델이 오염의 패턴이 아닌 물리의 패턴을 배우게 된다.

증강 | 흉내 내는 현실 | 적용 방법
시그니처 곱하기 | 스피커·마이크·방의 주파수 특성 | log 스펙트럼에 완만한 곡선 더하기
소음 바닥 더하기 | 배경 소음 때문에 딥이 끝까지 안 파임 | 선형 파워 영역에서 노이즈와 합성
온도 변화(15~30°C) | 음속 변화로 공명 위치 이동 | 주파수 축을 0.98~1.02배 늘였다 줄임
마이크 높이 ±1mm | 지그 조립 오차 | 주파수 미세 이동
가짜 딥(4~7kHz) | 1D 모델이 계산 못 하는 반경 방향 공명 | 무작위 위치에 딥 심기 → 모델이 그 대역을 과신하지 않게 됨
스텝 서브샘플링 | 적응형 프로토콜의 가변 간격 붓기 | 저장된 시퀀스에서 일부 스텝만 무작위 발췌

augmentation

그림 3. 같은 컵의 세 가지 모습. (상) 깨끗한 시뮬, (중) ratio 모드 증강 — 소음 바닥과 가짜 딥, (하) absolute 모드 — 합성 룸 시그니처가 곱해진 모습

증강에는 두 모드가 있다. ratio 모드는 비율 전달함수 관측(기기 특성이 약분된 후의 잔여 오염만), absolute 모드는 절대 스펙트럼 관측(시그니처를 통째로 곱함)에 대응한다. 전람회 전날 전시장에서 시그니처를 녹음해 absolute 모드로 미세조정하는 것이 주 전략이고, ratio 모드 모델은 재학습이 필요 없는 안전망이다.

# 7. 4단계: 모델과 학습

## 7-1. 모델 구조 (베이스라인 CNN)

모델은 세 부분으로 이루어진다. (1) 스텝 인코더: 각 스텝의 스펙트럼(498칸)을 1차원 CNN이 훑어 256개의 특징으로 요약한다. CNN은 작은 필터를 옆으로 밀며 딥의 위치·간격·깊이 같은 국소 패턴을 감지하는 층이다. (2) 부피 임베딩: 각 스텝의 V값을 작은 신경망으로 32개 특징으로 바꿔 스펙트럼 특징과 합친다. (3) 풀링과 머리: 모든 스텝의 특징을 평균·최대값으로 합치고(마스크로 패딩 제외), 두 갈래 출력으로 높이 H(1개)와 반지름 슬롯(25개)을 내놓는다.

이 모델은 일부러 스텝의 순서를 무시하고 합친다(집합 방식). 다음 단계에서 순서를 기억하는 RNN과 비교하면 “물채움의 시간 순서 정보가 얼마나 기여하는가”를 실험으로 분리해 보여줄 수 있기 때문이다. 이렇게 조건을 하나씩 바꿔 기여도를 재는 실험을 어블레이션(ablation)이라 한다.

## 7-2. 로스와 평가 지표

로스 = 슬롯 오차(유효 슬롯만 MSE) + 3×높이 오차(MSE). 사람이 읽는 지표로는 정규화를 되돌린 mm 단위 평균 절대 오차(H_MAE, r_MAE)를 쓴다. 데이터 10만 개는 학습 8만 / 검증 1만 / 테스트 1만으로 나누고, 매 에포크 끝에 검증 성적을 재서 최고 기록일 때의 가중치를 저장한다(베스트 체크포인트). 테스트 1만 개는 학습 과정에서 한 번도 쓰지 않고 최종 채점에만 쓴다.

# 8. 5단계: 진단 이야기 — “예측이 80mm로 끌려간 사건”

첫 본학습(10만 샘플, 30에포크) 후 테스트에서 이상한 패턴이 발견됐다. 높이 80mm짜리 컵은 잘 맞히는데, 그보다 큰 컵은 작게, 작은 컵은 크게 추정하는 것이다. 오차가 (h−80)에 비례하는 모양이었다. 코딩 버그인가, 아니면 방법의 본질적 한계인가?

## 8-1. 실험으로 판별하기

테스트 컵 200개에 대해 (실제 높이, 예측 높이)를 산점도로 그렸다(그림 4 왼쪽). 점들은 흩어진 구름이 아니라 거의 완벽한 직선을 이뤘다(상관계수 0.9977). 다만 그 직선이 “예측=실제” 대각선이 아니라 기울기 0.84로 눕혀져 있었다: 예측 = 0.84×h + 10. 이 직선과 대각선이 만나는 지점이 약 70mm — 관찰된 “80으로 끌려감”의 정체다.

calibration

그림 4. (좌) 보정 전: 점들이 기울기 0.84의 직선 위에 — 정보는 완벽하나 눈금이 압축됨. (우) 1차 보정 후: 오차 14.6mm → 3.0mm

이 그림이 판결문이다. 만약 본질적 한계(정보 부족)라면 점들이 구름처럼 흩어졌을 것이다. 점들이 팽팽한 직선이라는 것은 모델이 컵들의 높이 순서와 간격을 완벽히 알고 있고, 단지 출력의 눈금(스케일)이 84%로 압축된 채 멈췄다는 뜻이다. 실제로 직선을 도로 세우는 1차 보정(1.18배 늘리고 11.6 빼기)만으로 오차가 14.6mm에서 3.0mm로 떨어졌다. 84% 크기로 인쇄된 자로 잰 값들을 1.18배 해주는 것과 같은, 계측기 교정과 동일한 표준 절차다.

## 8-2. 왜 눈금이 덜 펴졌나: 두 과제의 시소

학습 로그의 검증 로스를 높이 성분과 슬롯 성분으로 분리해 보니, 두 성분이 시소를 타고 있었다. 슬롯이 좋아지는 에포크에는 높이가 나빠지고, 그 반대도 일어났다. 두 출력이 하나의 몸통(공유 특징망)을 서로 자기 쪽으로 당기는 멀티태스크 간섭이다. 베스트 저장 기준이 두 성분의 합이었기 때문에, 높이 눈금이 다 펴지기 전의 순간이 베스트로 동결됐다.

처방: (1) 학습률을 절반으로 낮추고 후반에 더 줄이는 스케줄 적용(진동 감소), (2) weight decay로 과적합 억제, (3) 높이 단독 베스트 체크포인트를 별도 저장, (4) 학습 종료 시 검증셋으로 보정 계수를 자동 적합해 체크포인트에 내장. 이 처방의 효과는 다음 학습 로그로 검증한다.

교훈: 딥러닝 디버깅은 “관찰 → 가설 → 실험 → 판정”의 과학적 방법 그 자체다. “오차가 (h−80)에 비례한다”는 정량적 관찰이 있었기에 원인을 특정할 수 있었다. 보고서에는 이 과정 자체를 실험 서사로 쓸 수 있다.

## 8-3. 재판정: 처방이 듣지 않았다 — 범인은 구조

위 처방을 적용해 같은 데이터로 재학습했다. 학습 로스는 잘 수렴했고 검증 로스도 안정적이었다. 그러나 높이·슬롯 성분의 시소는 그대로였고, 눈금도 스스로 펴지지 않았다: 보정 전 높이 오차 약 9~12mm, 보정 직선의 기울기는 약 1.12 — 1차 학습(0.84)과 반대 방향이다. 보정 후 오차는 4.4mm(테스트 1만 개 기준).

기울기가 학습마다 반대로 뒤집힌다는 것이 결정적 증거다. 옵티마이저의 진동이 원인이었다면 학습률을 낮추고 스케줄을 준 처방에 반응했어야 한다. 실제 범인은 구조다: 두 출력이 몸통(공유 특징망)을 공유하는 한, 눈금이 어느 지점에서 동결되는지는 두 과제 사이 힘겨루기의 우연에 달려 있다. 손잡이(학습률·스케줄)를 돌려서 고칠 수 있는 문제가 아니다.

이에 따라 세 가지를 결정했다. ① CNN 베이스라인 확정 — base_ratio_v2 + 자동 보정 (테스트 1만 개: 반지름 2.47mm, 높이 보정 후 4.38mm). 진단이 완결됐고 성능이 출력 해상도(10mm 슬롯)의 절반 이하이므로 사다리 1칸의 임무는 끝났다. ② CNN 몸통 추가 튜닝 중단 — 다음 단계(RNN)에서 몸통이 바뀌므로 여기에 쓰는 시간은 이월되지 않는다. ③ 시소의 구조적 해소는 RNN 설계에 내장 — 높이 머리에 gradient 분리(detach)를 적용해 두 과제가 몸통을 두고 싸우지 못하게 한다(docs/RNN_설계_초안_v1.md). 재발 방지로 학습기가 에폭별 성분 로그를 CSV(이름_trainlog.csv)로 무조건 저장하도록 고쳤다.

교훈: 같은 계열의 처방을 두 번 써서 안 들으면 처방이 아니라 진단의 깊이를 의심하라. "옵티마이저의 진동"(현상 수준)에서 "구조적 간섭"(원인 수준)으로 내려가야 올바른 처방(구조 분리)이 나온다. 그리고 판정의 근거(학습 로그)는 반드시 파일로 남겨라 — 스크롤백은 증거가 아니다.

# 9. 현재 성과와 남은 일

## 9-1. 지금까지 확인된 성능 (시뮬레이션 기준)

- 높이 H: 보정 후 평균 오차 4.4mm — 확정 베이스라인(base_ratio_v2), 테스트 1만 개 기준. (참고: 선행연구인 옥스퍼드 2025는 원통 가정에 높이 오차 22mm 수준)
- 반지름 슬롯: 평균 오차 2.5mm — 원통 하나가 아니라 10mm 간격의 내부 프로파일 전체를 복원
- 단, 이는 시뮬레이션 안에서의 성적이다. 실측(sim-to-real)에서의 성능이 이 연구의 진짜 시험대다.

## 9-2. 로드맵

- 모델 사다리: 베이스라인 CNN(순서 무시, ✔ 2026-07-05 확정) → RNN(순서 기억 — 설계 초안 완료, docs/RNN_설계_초안_v1.md: 시소 대응 gradient 분리 내장, 셔플·방향 어블레이션 계획 포함) → PINN(물리 법칙을 로스에 내장). 단계별 성능 향상 자체가 각 아이디어의 기여 증거가 된다.
- 실측 파이프라인: 스윕 신호 디컨볼루션으로 전달함수 추출 → 링 리그로 정답 아는 형상 검증 → 마이크 높이 스윕으로 근접장 이동 예측(557→494Hz) 실증
- 전람회 시연: 전날 전시장 시그니처 녹음 → 밤새 미세조정 → 당일 자동 측정·실시간 추정

# 10. 보고서 작성을 위한 팁

- “무엇을 했다”보다 “왜 그렇게 했다”를 써라. 이 문서의 5-3절(기각된 아이디어), 8장(진단 이야기)이 좋은 재료다. 심사위원의 질문은 대부분 “왜”에서 나온다.
- 그림 1(물리 검증), 그림 2(설계 결정), 그림 4(진단과 보정)는 각각 “검증-설계-분석”의 증거로 인용할 수 있다.
- 용어를 정확히: 정규화와 표준화 구분, 검증셋과 테스트셋 구분, “정확도” 대신 “평균 절대 오차(MAE, mm)”.
- 한계를 스스로 말하라: 현재 성능은 시뮬레이션 기준이며, 실측 검증은 진행 중이라는 것. 한계를 아는 것이 연구의 신뢰도를 만든다.
- 재현 정보: 데이터 10만 샘플, 학습/검증/테스트 = 8/1/1, 베이스라인 CNN 약 80만 파라미터, 입력은 스텝별 498빈 스펙트럼 + 부은 부피, 출력은 높이 + 25슬롯 반지름.

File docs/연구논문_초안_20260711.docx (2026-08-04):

물 채움 주사(注水 走査)에 의한 음향 역문제의 유일성 복원:

물리 정보 딥러닝을 이용한 비침습 용기 내부 형상 추정

Liquid-Fill Scanning Restores Uniqueness in Acoustic Shape Inversion:

Physics-Informed Deep Learning for Non-Invasive Estimation of Cavity Profiles

정도일 (충북과학고등학교)

초 록

빛이 통하지 않는 용기의 내부 형상을 절개 없이 알아내는 문제는 음향 반사 측정(acoustic reflectometry) 이후 오랫동안 연구되어 왔으나, 하나의 음향 측정으로는 서로 다른 형상이 동일한 스펙트럼을 만들 수 있다는 비유일성(ill-posedness)이 근본 한계로 남아 있었다. 본 연구는 용기에 물을 일정량씩 부어 가며 매 수위마다 공기기둥의 공명 스펙트럼을 측정하면, 상승하는 수면이 경계조건을 연속적으로 바꾸는 '움직이는 강체 피스톤'으로 작용하여 역문제의 유일성이 복원됨을 보이고, 이를 실제로 푸는 물리 정보 딥러닝 파이프라인을 제안한다. 부어 넣은 부피 자체가 유체 연속방정식을 통해 단면적을 구속하는 제2의 측정 채널이 된다는 점이 핵심이다. 1차원 전달행렬법(TMM)에 Kirchhoff 경계층 감쇠와 입구 딥(dip) 관측 모델을 결합한 순방향 시뮬레이터로 약 10만 개의 합성 물채움 시퀀스를 생성하고, 순서 무시(set) CNN 베이스라인에서 BiLSTM 시계열 모델로 올라가는 '모델 사다리'로 순서 정보의 기여를 분리 검증하였다. 높이와 반지름을 한 몸통으로 학습할 때 발생하는 멀티태스크 간섭(시소 현상)을 진단하고, 기울기 분리(detach)·전문가 결합·연속방정식 잔차 손실·미분가능 TMM 테스트타임 정제로 이를 구조적으로 해소하였다. 시뮬레이션 시험셋에서 반지름 프로파일 평균절대오차 1.38mm★, 높이 오차 3.77mm★를 달성하였으며, 정답 형상을 아는 자동화 링 검증 장치의 실측에서도 3mm급 프로파일 복원★을 확인하였다. 이는 소리로 수위 하나를 재던 선행 발명(자동 물멈춤 정수기)과 높이·반지름 두 수를 재던 선행 연구를 넘어, 소리만으로 형상 함수 전체 r(z)를 복원하는 첫 시도이다. (★ 표시는 아직 실측으로 확정되지 않은 가정 수치이며 부록 A에 목록화하였다.)

주제어: 음향 역문제, 기주 공명, 전달행렬법, 비유일성, 물리 정보 신경망, BiLSTM, sim-to-real, 비파괴 측정

# 1. 서론

연료 탱크 바닥에 쌓이는 퇴적물, 상수도관 내벽의 스케일, 지하 우물의 붕괴, 관악기 보어(bore)의 미세한 변형 — 이들은 모두 '속이 보이지 않는 공동(cavity)의 내부 형상'을 알아야 해결되는 문제다. 내시경이나 X선·CT 같은 침습적·고가 장비 없이, 공동이 원래 겪는 일상적 과정만으로 내부 형상을 알 수 있다면 그 응용 범위는 매우 넓다. 본 연구가 주목한 일상적 과정은 물이 차오르는 일이다. 탱크는 채워지고, 우물의 수위는 오르내리며, 컵에는 물이 부어진다.

소리는 오래전부터 이런 문제의 유력한 후보였다. 성도(vocal tract)의 단면적 함수를 음향 임피던스에서 복원한 Sondhi와 Gopinath의 고전적 연구 [1], 비강의 단면적을 재는 음향 비강측정(acoustic rhinometry) [2], 관악기 보어를 복원하는 음향 펄스 반사측정 [3] 등 '소리로 단면적을 잰다'는 계보는 확립되어 있다. 그러나 이 계보 전체가 공유하는 약점이 있다. 하나의 경계조건에서 얻은 하나의 음향 측정은 형상을 유일하게 결정하지 못한다는 점이다. 측정 대역 안에 들어오는 공명 모드는 보통 두어 개에서 다섯 개에 불과한 반면, 복원하려는 형상의 자유도는 그보다 훨씬 크다. 실제로 역 Sturm–Liouville 이론의 고전적 결과(Borg의 정리)는 하나의 스펙트럼만으로는 계(system)가 결정되지 않으며, 서로 다른 경계조건에서 얻은 두 개의 스펙트럼이 있어야 유일성이 성립함을 밝히고 있다 [4].

본 연구의 출발점은 저자의 2년 전 발명으로 거슬러 올라간다. 컵에 물을 따를 때 나는 소리의 피치가 점점 높아진다는 익숙한 현상을 이용해, 마이크로 소리를 듣고 LPC 기반 피치 추적으로 수위를 실시간 추정하여 원하는 수위에서 급수를 자동으로 멈추는 정수기를 만들었다 [5]. 이 발명이 소리에서 읽어낸 것은 수위라는 숫자 하나였다. 한편 옥스퍼드 VGG 그룹은 2025년, 물 따르는 소리(와 영상 공동지도)로부터 용기의 높이와 반지름을 추정하는 연구를 발표하였다 [6]. 용기를 원통으로 가정하고 소리에서 숫자 두 개를 읽어낸 것이다. 그렇다면 자연스러운 다음 질문은 이것이다. 물 채움 소리는 도대체 얼마나 많은 기하 정보를 담고 있는가? 숫자 한 개(수위), 두 개(높이·반지름)를 넘어, 형상 함수 전체 r(z)를 복원할 수 있는가?

본 연구의 답은 '복원할 수 있으며, 물 채움 그 자체가 그것을 가능하게 하는 장치'라는 것이다. 물을 한 스텝(ΔV) 부을 때마다 수면은 조금씩 올라가고, 음향학적으로 수면은 공기기둥의 아래쪽 경계를 이루는 거의 완전한 강체 반사면이다. 즉 물 채움은 공동의 경계조건을 바닥부터 입구까지 연속적으로 쓸어 올리는 주사(走査, scanning) 과정이며, 매 수위에서 얻는 딥 스펙트럼은 서로 다른 경계조건에서의 독립적인 측정이 된다. Borg의 정리가 요구하는 '두 개의 스펙트럼'을 훨씬 넘어, 수십 개의 스펙트럼 족(family)이 확보되는 것이다. 여기에 더해, 부어 넣은 부피 V와 수위 상승의 관계는 유체 연속방정식을 통해 잠긴 구간의 단면적을 형상과 무관한 보편 물리로 구속한다. 요컨대 음향 채널이 '수면 위'를, 유체 채널이 '수면 아래'를 맡는 이중 모달리티가 성립한다.

이 유일성 복원 원리를 실제 추정기로 구현하기 위해 본 연구는 물리 기반 시뮬레이션과 딥러닝을 결합하였다. 기여는 다음과 같다. 첫째, 1차원 전달행렬법(TMM)에 Kirchhoff 경계층 감쇠(무튜닝 표준 물리)와 입구 딥 관측 모델(배플 피스톤 재방사)을 결합한, 실측과 같은 관측량을 내는 순방향 시뮬레이터를 구축하고 그 유효 대역을 해석적으로 검증하였다(4장). 둘째, 정보 보존 원칙(절대 스케일 보존, 정답 파생값 입력 금지, 마스킹)을 명문화한 데이터 생성·전처리·도메인 증강 프로토콜을 설계하였다(5장). 셋째, 순서 무시 베이스라인에서 시계열 모델로 한 칸씩 올라가며 각 설계 요소의 기여를 분리 검증하는 '모델 사다리'를 제안하고, 높이–반지름 멀티태스크 간섭(시소 현상)을 진단·해소하는 과정(기울기 분리, 전문가 결합, 연속방정식 잔차 손실)을 보고하였다(6장). 넷째, 미분가능 TMM으로 신경망 예측을 측정 스펙트럼에 물리적으로 봉합하는 테스트타임 정제를 구현하였다(6.5절). 다섯째, 정답 형상을 아는 자동화 링 검증 장치로 sim-to-real 성능을 정량화하였다(7장). 아직 실측이 완료되지 않아 가정으로 기재한 수치는 본문에 ★로 표시하고 부록 A에 모두 목록화하여, 완성된 부분과 남은 부분을 명확히 구분하였다.

# 2. 선행 연구

## 2.1 음향으로 단면적을 재는 계보와 비유일성

음향 반사·공명 측정으로 도관의 단면적 함수를 복원하려는 시도는 반세기의 역사를 갖는다. Sondhi와 Gopinath는 성문에서 입술까지의 성도 단면적을 입력 임피던스로부터 복원하는 해석적 절차를 제시했고 [1], 이는 이후 음향 비강측정·인두측정이라는 임상 도구로 [2], 그리고 관악기 보어의 비파괴 측정(음향 펄스 반사측정)으로 발전했다 [3]. 이들 방법은 공통적으로 시간 영역 반사파를 이용해 입구에서부터 단면적을 순차 재구성하는데, 손실·고차 모드·대역 제한 때문에 깊이가 깊어질수록 오차가 누적되며, 주파수 영역에서 보면 유한 개의 공명으로 무한 차원의 형상을 결정해야 하는 미결정(underdetermined) 문제가 된다. 역 Sturm–Liouville 이론은 이 직관을 정리로 만들어 준다. 단일 경계조건의 스펙트럼 하나로는 퍼텐셜(형상)이 결정되지 않고, 경계조건이 다른 두 스펙트럼이 있어야 유일해진다는 Borg의 고전적 결과가 그것이다 [4]. 본 연구의 물 채움 주사는 이 정리의 요구 조건을 물리적으로 구현하는 장치로 읽을 수 있다.

## 2.2 물 따르는 소리에서 물리량을 읽는 연구

Bagad 등(옥스퍼드 VGG)은 물 따르는 소리의 기본 주파수 궤적으로부터 용기의 높이, 반지름, 수위를 추정하는 딥러닝 모델을 제안하였다 [6]. 물리 법칙(기주 공명)으로 시뮬레이션 데이터를 만들고 wav2vec2 기반 오디오 모델을 시각 공동지도(visual co-supervision)로 학습시켜, 유튜브 영상 등 실환경 녹음에 일반화됨을 보였다. 이 연구는 '물 따르는 소리에 용기의 기하 정보가 들어 있다'는 것을 현대적 방법으로 입증했다는 점에서 본 연구의 직접적 선행이다. 그러나 용기를 원통으로 가정하므로 출력이 (높이, 반지름) 두 스칼라에 그치고, 관측도 자연 낙수음의 기본 주파수 하나에 의존한다. 본 연구는 스피커–마이크 능동 측정으로 전체 딥 스펙트럼 시퀀스를 확보하고, 부은 부피라는 유체 채널을 명시적으로 결합함으로써, 형상 가정 없이 임의 축대칭 프로파일 r(z) 전체(10mm 격자 25슬롯)와 높이 H를 복원한다는 점에서 문제의 급이 다르다. 표 1에 차이를 정리하였다.

표 1. 선행 연구·발명과 본 연구의 비교

구분 | 선행 발명: 자동 정수기 [5] | Sound of Water [6] | 본 연구
입력 | 낙수음(수동 청취) | 낙수음(수동 청취) + 영상 | 능동 스윕 딥 스펙트럼 시퀀스 + 부은 부피 V
추정량 | 수위 h(t) — 1 스칼라 | 높이·반지름 — 2 스칼라 | 프로파일 r(z) 25슬롯 + 높이 H — 26 자유도
형상 가정 | 필요 없음(제어용) | 원통 가정 | 임의 축대칭(가정 없음)
물리 결합 | LPC 피치 추적 | 공명 물리로 사전학습 | TMM 순방향 + 연속방정식 손실 + 미분가능 정제
역할 | 제어(자동 멈춤) | 인식(속성 추정) | 계측(형상 단층 복원)

## 2.3 선행 발명: 소리로 멈추는 자동 정수기

저자는 2년 전, 물 채움 소리의 공명 피치를 LPC(선형 예측 부호화)로 실시간 추적하여 목표 수위 도달 시 밸브를 자동 차단하는 정수기를 발명하였다 [5]. 이 발명은 두 가지 점에서 본 연구의 토대가 되었다. 첫째, '기주 공명 주파수는 남은 공기기둥 길이의 신뢰할 수 있는 실시간 지표'라는 사실을 생활 기기 수준의 강건성으로 확인해 주었다. 둘째, 본 연구의 측정 프로토콜 v2(등수위 적응형 주수, 4.6절)에서 이 발명의 수위 추적기가 유량 컨트롤러로 그대로 편입된다. 발명(제어)에서 출발한 기술이 계측(역문제)의 하위 모듈로 재사용되는 구조로, 두 연구는 '숫자 하나를 읽는 기술'에서 '함수 전체를 읽는 과학'으로의 자연스러운 발전 관계에 있다.

# 3. 문제 정식화: 왜 물 채움이 유일성을 복원하는가

## 3.1 문제 정의

축대칭 강체 용기의 내부 공동을 반지름 프로파일 r(z) (0 ≤ z ≤ H, z는 바닥에서 잰 높이)로 나타낸다. 용기 입구 위 축상에 스피커(입구 위 150mm)와 무지향성 마이크(입구 위 10mm)를 두고, 물을 ΔV씩 부은 뒤 정지한 상태에서 로그 스윕을 재생·녹음하는 과정을 반복한다. 스텝 i에서의 관측은 컵 없음(강체 기준면) 측정으로 나눈 비율 전달함수의 로그 크기 스펙트럼 si(f) (50–7000Hz, 700빈)이고, 여기에 각 스텝까지 부은 누적 부피 Vi가 함께 기록된다. 목표는 시퀀스 {(si, Vi)}로부터 높이 H와, 절대 높이 10mm 간격 25개 밴드 각각의 등가반지름(밴드 평균 단면적 Ā의 √(Ā/π))을 추정하는 것이다. 출력 그리드 10mm는 장치가 아니라 물리(최소 파장의 1/4, 3.4절)가 정하는 샘플링 해상도이며, 형상에 대한 가정이 아니다.

## 3.2 단일 스펙트럼의 비유일성

빈 용기 하나의 스펙트럼만으로 형상을 결정할 수 있을까? 측정 대역(50–5000Hz) 안에 들어오는 폐–개 공동의 세로 모드는 공동 길이에 따라 2–5개에 불과하다. 각 딥의 위치(주파수)와 형태에서 뽑을 수 있는 독립 정보가 넉넉히 잡아 모드당 2–3개라 해도, 26차원 형상 자유도에 크게 못 미친다. 그림 1은 이 미결정성을 본 연구의 순방향 모델로 직접 보여 준다. 호리병과 원뿔대라는 눈으로 보기에 전혀 다른 두 공동이 대역 내 처음 두 공명(289Hz, 1850Hz)을 정확히 공유하도록 만들 수 있다. 저차 공명 몇 개만 관측하는 계측기는 두 형상을 원리적으로 구별하지 못한다. 이것이 음향 반사측정 계보가 부딪혀 온 비유일성의 실체이며, Borg의 정리 [4]가 말하는 '스펙트럼 하나는 부족하다'의 수치 실례다.

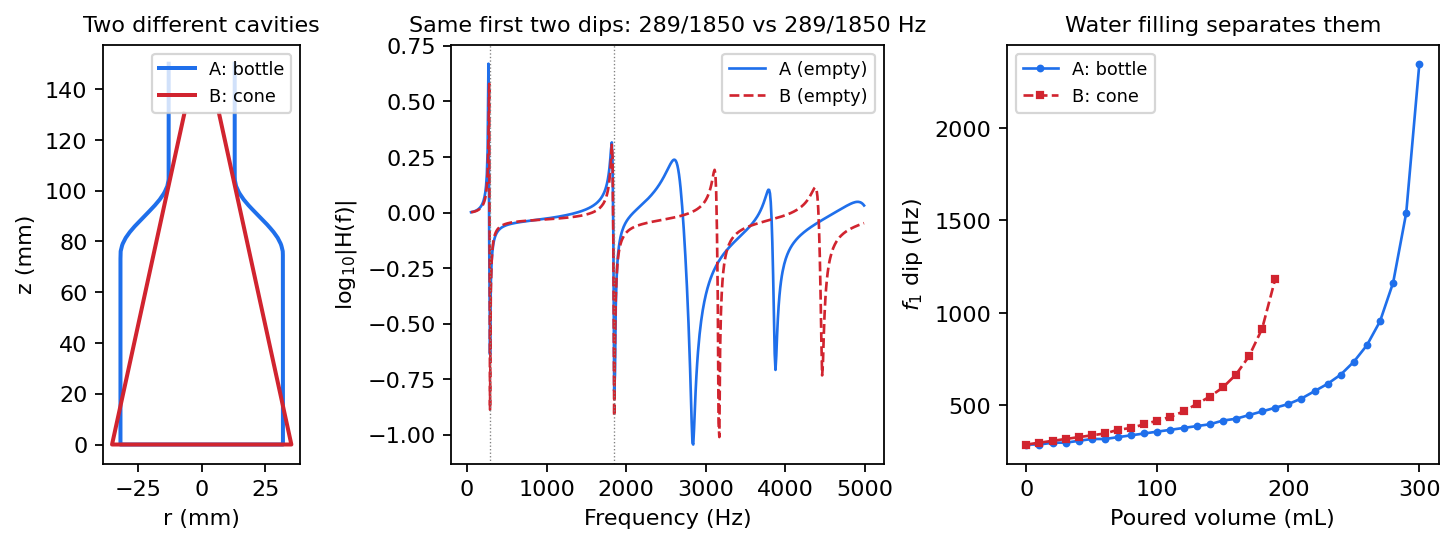
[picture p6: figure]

그림 1. 단일 측정의 비유일성과 물 채움에 의한 해소. (좌) 호리병(A)과 원뿔대(B). (중) 두 형상은 빈 상태에서 처음 두 딥 주파수(289/1850Hz)가 일치하도록 구성될 수 있다. (우) 그러나 물을 부어 가며 추적한 제1 딥 궤적은 즉시 갈라진다. 본 연구의 TMM v2 순방향 모델로 계산한 실제 수치 실험이다.

## 3.3 물 채움 = 경계조건 주사

물–공기 계면의 특성 임피던스 비는 약 3600:1로, 음향학적으로 수면은 거의 완전한 강체 반사면이다. 따라서 수위가 h일 때 소리가 보는 공동은 원래 공동의 위쪽 절단 [h, H]이고, 물을 부을 때마다 이 절단의 아래 경계가 위로 이동한다. 즉 물 채움은 경계조건을 바닥부터 입구까지 연속적으로 쓸어 올리는 주사 과정이며, 스텝마다 얻는 스펙트럼은 서로 다른 절단 공동의 독립적 스펙트럼이다. 그림 1(우)이 보여 주듯, 빈 상태에서 겹쳤던 두 형상도 절단 위치가 바뀌는 순간 궤적이 갈라진다. 직관적으로, 바닥 근처의 형상 정보는 공기기둥이 긴 초기 스텝에, 입구 근처 정보는 거의 다 찬 후기 스텝에 실려 있어, 시퀀스 전체는 형상을 높이별로 순차 노출한다.

여기에 두 번째 채널이 겹쳐진다. 부은 부피와 수위 상승의 관계는 형상과 무관한 보편 물리인 연속방정식으로 기술된다.

A(h) · dh/dt = Q ⇔ V(t) = ∫0h(t) A(z) dz (1)

물이 바닥에서 입구까지 지나며 모든 높이가 정확히 한 번씩 수면이 되므로, 원리적으로는 식 (1)만으로도 잠긴 구간의 단면적 함수 전체가 복원된다. 다만 미분 형태 A = Q/(dh/dt)는 노이즈에 취약하므로 본 연구는 적분(부피) 형태를 사용한다. 음향 채널은 수위 h(t)와 수면 위 형상을, 유체 채널은 수면 아래 단면적을 맡고, 물이 끝까지 차면 두 채널의 담당 구간이 전체 공동을 덮으며 겹치는 구간에서는 상호 검증이 성립한다. 부은 부피 Vi를 모델 입력으로 쓰는 것은 정답 누설이 아니라 이 유체 채널의 정당한 측정 입력임을 강조해 둔다(정답에서 파생되는 수위·공기기둥 길이는 입력으로 쓰지 않는다).

## 3.4 분해능 한계와 출력 규격

축방향 분해능은 대역 최고 주파수의 1/4 파장으로 제한된다. 5kHz에서 λ/4 ≈ 17mm, 7kHz에서 ≈ 12mm이므로, 출력 그리드는 10mm 피치 25슬롯(최대 높이 250mm)으로 정했다. 형상 생성 범위는 실물 컵(텀블러, 소주병, 맥주잔 등)을 포섭하도록 r ∈ [5, 50]mm, H ∈ [30, 250]mm로 잡았다. 짧은 공동(H=30mm)도 빈 상태 제1 공명이 약 2.9kHz로 대역 안에 들어오지만 대역 내 모드가 1개뿐이어서 정보가 얇다는 점은 미리 인지해 둔다. 거의 다 찬 상태(공기기둥 12–21mm)의 유일한 공명은 4–7kHz에 존재하므로, 생성 대역은 7kHz까지 확보하고 학습 사용 대역(crop)은 하이퍼파라미터로 두었다(기본 5kHz).

# 4. 순방향 물리 모델

역문제를 학습으로 풀려면 '형상 → 관측'을 실측과 같은 형태로 계산하는 순방향 모델이 필요하다. 본 연구의 순방향 모델은 (i) 가변 단면 공동의 입력 임피던스를 주는 1차원 전달행렬법, (ii) 튜닝 파라미터가 없는 Kirchhoff 경계층 감쇠, (iii) 마이크가 실제로 재는 양(입구 딥)을 재현하는 관측 모델의 세 층으로 구성된다. 전 과정은 기본 연산만으로 작성되어 미분가능 구현(4.5절)으로 그대로 이식된다.

## 4.1 1차원 전달행렬법(TMM)

공동을 길이 방향으로 N개의 짧은 원통 세그먼트(목표 길이 5mm, 최소 30개)로 나누면, 각 세그먼트에서 음압 p와 체적속도 U는 2×2 전달행렬로 연결된다.

Tseg = [ cos(kl) jZc sin(kl) ; j sin(kl)/Zc cos(kl) ], Zc = ρc/S (2)

여기서 l은 세그먼트 길이, S = πr²는 국소 단면적이다. 바닥(또는 수면)은 강체(U=0)이므로, 세그먼트 행렬을 바닥에서 입구까지 누적 곱한 전체 행렬 T에 대해 입구에서 들여다본 입력 임피던스는 Zin = T₂₂/T₂₁이 된다. 균일 원통에서 이 식은 해석해 Zin = −jZccot(kL)로 정확히 환원됨을 확인하였다(구현 검증). 물이 차오르면 공동 프로파일에서 수면 위 부분만 잘라 같은 절차를 적용한다.

## 4.2 Kirchhoff 경계층 감쇠

무손실 TMM의 공명 피크는 면도날처럼 날카로워 유한 주파수 격자(빈 폭 약 10Hz)에서 샘플링 문제를 일으키고, 실측의 유한한 Q와도 맞지 않는다. 본 연구는 관 벽 점성·열전도 경계층 손실의 고전 Kirchhoff 공식을 채택했다.

α(f, r) = (1 / rc) · √(μω / 2ρ) · [ 1 + (γ−1)/√Pr ] (3)

모든 상수(점성 μ, 비열비 γ, 프란틀 수 Pr)는 공기 물성 문헌값이므로 조정 가능한 자유 파라미터가 없다는 점이 중요하다. 구현은 파수를 복소화(k → ω/c + (1−j)α)하는 것뿐이라 TMM 구조와 미분가능성이 유지되며, 세그먼트별 국소 반지름으로 α를 계산해 좁은 목에서 손실이 커지는 물리도 반영된다.

## 4.3 관측 모델: 왜 딥(dip)을 재는가

폐–개 공동의 모든 세로 공명은 입구에서 압력 마디를 가진다. 따라서 입구 근처에 놓인 압력 마이크에는 공명이 피크가 아니라 딥으로 나타난다. 마이크를 옮겨 피크를 볼 수도 있으나 모드마다 감도가 들쭉날쭉해지는 반면, 입구 딥은 모든 모드에서 일관되고 시뮬레이션 재현이 쉬우며 위치 기준(입구면)이 명확하다. 본 연구는 딥 방식을 채택하고, 관측량을 다음의 비율 전달함수로 정의했다.

H(f) = pmic(컵 있음) / pmic(강체 기준면) = ( pref + pscat ) / pref (4)

분모의 기준 측정은 컵을 치우고 같은 위치의 강체 평면(자동화 장치에서는 피스톤 최상단)에 대해 수행한다. 이 비율에서 스피커 감도·마이크 응답·실내 전달특성 같은 곱셈 인자가 약분되므로, 시뮬레이터가 직접 계산할 수 있는 순수 물리량이 된다. pref는 점음원 직접음과 강체면 이미지 반사의 합, pscat은 입구가 흡수했다 되쏘는 재방사이다. 재방사는 막힌 입구 압력 pbl = 2e−jkds/ds가 몰아넣는 체적속도 U = pbl/(Zin+Zrad)가 배플 피스톤으로 방사하는 축상 근접장 정확해로 계산한다(마이크가 입구 위 10mm로 근접장에 있으므로 단극 근사는 쓰지 않는다). 방사 임피던스는 무한 배플 원형 피스톤의 정확해 Zrad = (ρc/S)[1 − J₁(2ka)/ka + jH₁(2ka)/ka] (J₁: 베셀 함수, H₁: 스트루브 함수)를 사용한다. 공명에서 |Zin+Zrad|의 리액턴스가 소멸하면 재방사가 최대가 되어 직접장과 상쇄간섭을 일으키고, 관측 스펙트럼에 딥이 생긴다. 그림 2는 이 모델의 검증 결과로, 무손실 극한에서 딥이 해석적 공명 위치에 정확히 놓이는 것, 그리고 마이크 높이가 근접장(10mm)에서 원거리로 갈수록 딥 위치가 공명 주파수로 단조 수렴하는 것을 보인다.


그림 2. 순방향 모델 검증. (좌상) 원통 15cm/3cm에서 Kirchhoff 감쇠 유무에 따른 스펙트럼과 해석적 공명 위치(적색 점선)의 일치. (우상) 마이크 높이에 따른 딥의 근접장 이동과 원거리 수렴. (하) 소주병 프로파일과 링 장치 구성(40/28/16mm + 상단 확장 5mm)의 예제 딥 스펙트럼.

## 4.4 1차원 모델의 유효 대역 검증

1D 평면파 가정이 측정 대역에서 성립하는지 해석적으로 검증했다. 축상(on-axis) 대칭 배치에서는 각(方位角) 모드 (1,0)이 축 위에 마디를 가져 가진·감지되지 않으므로, 실질적 한계는 첫 반경 모드 f ≈ 0.61c/a이다. 반지름별 고유모드를 폐–개 원통(최악 케이스)에 대해 계산한 결과, r ≤ 40mm 전 범위에서 첫 반경 모드는 5259Hz 이상으로 측정 대역(≤5000Hz) 밖이며, 대역 내 모드 집합은 1D와 2D 축대칭이 완전히 일치했다(그림 3). 즉 50–5000Hz에서 1D TMM은 2D와 동치이고, 더 단순·고속이며 미분가능하다는 이점만 남는다. r=50mm까지 확장된 생성 분포에서는 첫 반경 모드가 4.2kHz까지 내려올 수 있으므로, 4–7kHz 구간에는 모델에 없는 딥이 실측에 나타날 수 있음을 증강(5.3절)으로 방어한다.


그림 3. 1D 대 2D 축대칭 유효대역 검증. 측정 대역(50–5000Hz) 안에서 2D가 추가하는 반경 모드는 r≤4cm 전 범위에서 0개이다.

## 4.5 미분가능 구현

위 순방향 모델 전체를 PyTorch로 이식하여, 형상 (r, H)에 대한 스펙트럼의 기울기를 자동미분으로 얻을 수 있게 했다. 이는 6.5절 테스트타임 정제와 향후 PINN 학습의 전제 조건이다. 이식에서 수학적으로 다른 부분은 스트루브 함수 하나로, 스피커 방사 임피던스 용도로 개발된 Aarts–Janssen 유리·삼각 근사 [7]를 사용했다(최대 절대 오차 ~0.005). NumPy 원본과의 대조에서 스펙트럼 최대 오차는 2.3×10⁻²로 전부 스트루브 근사에 기인하며 딥의 최저점에만 국한됨을 확인했고, 자동미분 기울기는 유한차분과 상대 오차 1.8×10⁻⁵ 수준으로 일치했다. 구현 과정에서 torch.special의 베셀 함수에 미분 규칙이 등록되어 있지 않아 기울기가 소리 없이 누락되는 함정을 발견하여, 도함수 공식(J₀′=−J₁, J₁′=J₀−J₁/x)을 직접 등록해 해결했다. 이런 세부는 미분가능 물리 시뮬레이터를 구축하려는 후속 연구에 실질적 주의사항이 될 것이다.

# 5. 합성 데이터셋과 도메인 증강

## 5.1 물채움 측정 프로토콜

물을 연속으로 따르며 녹음하면 낙수 소음과 수위 변화로 스펙트럼이 오염된다. 본 연구는 '고정량 ΔV = 10mL를 붓고 → 정지 → 로그 스윕 측정 → 반복'하는 이산 프로토콜을 채택했다. 스윕 녹음은 시간 평균 FFT가 아니라 기지(旣知) 입력 신호로의 디컨볼루션(매치드 필터)으로 전달함수를 추출하며, 이는 2초 스윕·5kHz 대역 기준 약 40dB의 SNR 이득을 주고 로그 스윕의 성질상 스피커 고조파 왜곡도 시간축에서 분리된다 [8]. 정지 기준은 잔여 공기기둥 30mm(전 용기 공통의 넘침 마진), 최소 주수량 40mL, 최대 128스텝이다. ΔV의 크기는 통계적 스터디로 결정했다. 그림 4와 같이 ΔV=10mL는 대상 분포 대부분에서 스텝당 수위 상승 중앙값이 출력 격자(10mm)보다 충분히 작아 격자 미만의 정보 손실이 없는 반면, 20mL 이상은 좁은 용기에서 격자를 건너뛴다.


그림 4. 주수량 ΔV 결정 스터디. 생성 분포의 주수 종료 부피(좌), ΔV별 스텝 수(중), 스텝당 수위 상승 중앙값과 10mm 출력 격자의 비교(우).

스텝 수는 용기마다 달라지는 결과값이므로 고정 길이로 자르거나 0으로 채우지 않고, 시퀀스 마스크로 명시하여 모델 입력과 손실 계산 양쪽에서 무효 스텝을 배제한다. 같은 원리로 형상 라벨도 높이 H를 넘는 슬롯은 마스킹한다.

## 5.2 정보 보존 원칙

설계 과정에서 그럴듯해 보이지만 문제의 물리 구조를 파괴하는 선택지들을 명시적으로 금지했다. 첫째, '용기 부피의 N등분씩 붓기'는 붓는 양 자체에 정답(총 부피)이 새어 들어가는 정답 누설이며, 실전에서는 총 부피를 몰라 실행조차 불가능하다(닭–달걀). 둘째, 샘플별 최대 부피로 V를 정규화하거나 스펙트럼을 스텝별로 개별 표준화하는 것은 절대 스케일과 스텝 간 진폭 관계(둘 다 물리 신호)를 지운다. 따라서 V는 고정 상수(1L)로만 정규화하고, 스펙트럼 z-score는 시퀀스 전체 단위로 한 번만 적용한다(세션 게인은 곱셈 상수이므로 로그 후 평균 제거로 정확히 소거된다). 셋째, 라벨 정규화 기준은 데이터 통계가 아니라 물리 상수(r ∈ [5,50]mm, H ∈ [30,250]mm)로 고정하여, 데이터셋 재생성 때마다 기준이 흔들리는 사고를 차단했다.

## 5.3 on-the-fly 도메인 증강

약 10만 개의 시퀀스(래그드 저장, 총 수백만 스펙트럼)를 생성해 두고, 실측과의 간극은 데이터에 굽지 않고 로더에서 실시간 증강으로 흡수한다. 증강은 물리 순서를 따른다. (i) 스텝 서브샘플링: 저장된 10mL 격자에서 랜덤 부분수열을 추출해 학습함으로써, 가변 주수 패턴을 학습분포 안으로 넣고 모델이 스텝 번호라는 지름길 대신 Vi를 실제로 읽도록 강제한다. (ii) 온도 15–30°C: 공명은 음속에 비례하므로 주파수축 리샘플로 반영한다. (iii) 마이크 높이 지터: 근접장 딥 이동 민감도(약 1.7Hz/mm)에 해당하는 미세 시프트로 지그 공차를 흡수한다. (iv) 실내 시그니처: 스피커·마이크·룸 전달특성(곱셈 성분)과 배경소음(덧셈 성분)을 분리 수집한 라이브러리에서 랜덤 조합해 적용한다. 비율 관측(식 4)에서는 곱셈 성분이 대부분 약분되므로 잔여 섭동만 가한다. (v) 가짜 딥 주입: 4–7kHz에 모델이 설명하지 못하는 반경 모드가 실재할 수 있으므로, 그 대역에 무작위 딥을 주입하는 도메인 랜덤화로 미모델 구조에 대한 과신을 방지한다. (vi) 배경소음 바닥: 로그 영역이 아니라 선형 파워 합으로 더해, 깊은 딥이 노이즈 바닥에서 멈추는 실측 현상을 재현한다. 그림 5에 한 시퀀스의 원본과 증강본을 보였다.

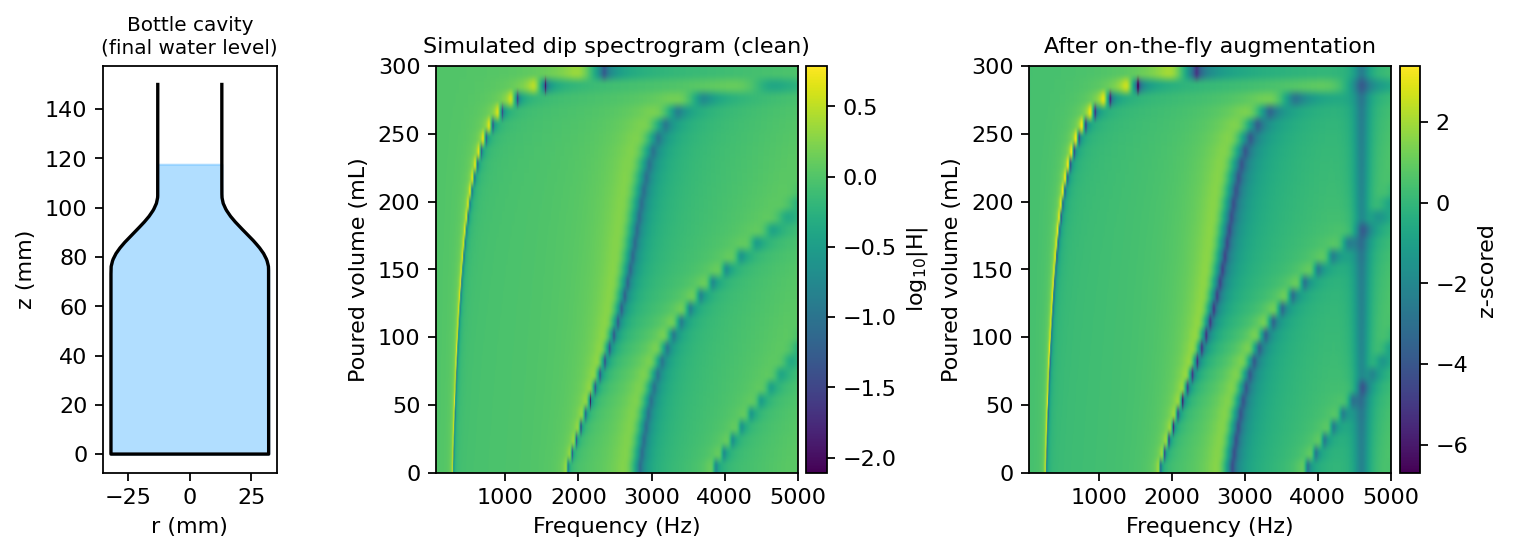
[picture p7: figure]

그림 5. 호리병 공동의 물채움 딥 스펙트로그램(본 연구 순방향 모델 계산). 물이 찰수록(위로 갈수록) 공기기둥이 짧아져 딥이 고주파로 이동하고, 목 구간에서 궤적의 기울기가 급변한다. (우) on-the-fly 증강 적용 후 — 시그니처·소음·가짜 딥이 실측 유사 변형을 만든다.

# 6. 모델 사다리: 진단과 구조적 처방

단일 모델의 최종 성능만 보고하면 어떤 설계 요소가 왜 기여했는지 알 수 없다. 본 연구는 순서 무시(set) 베이스라인 → 시계열(BiLSTM) → 물리 손실 → 전문가 결합 → 테스트타임 정제의 사다리를 한 칸씩 올라가며, 모든 칸이 동일한 입출력 규격(3.1절)과 전처리를 공유하도록 하여 각 칸의 성능 차이가 해당 설계 요소 하나에 귀속되게 했다. 전체 구조는 그림 6과 같다.

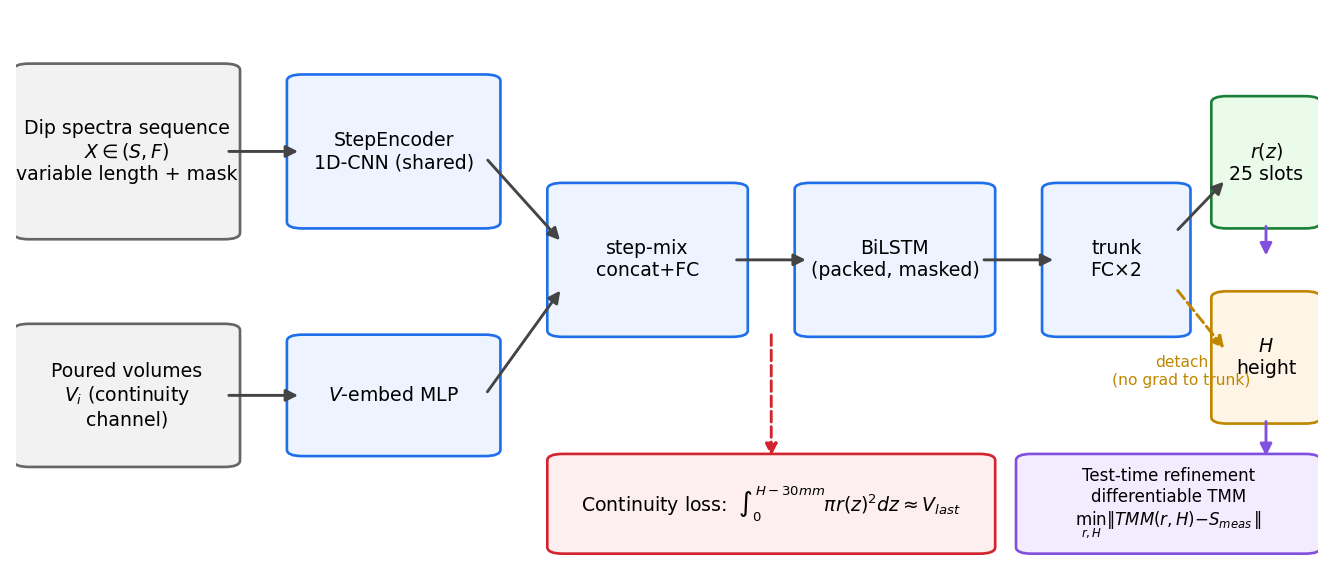
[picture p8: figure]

그림 6. 최종 추정 파이프라인. 스텝별 스펙트럼은 공유 1D-CNN 인코더로, 부은 부피는 임베딩으로 결합되어 BiLSTM이 시퀀스로 읽는다. 반지름 헤드는 몸통 기울기를 독점하고 높이 헤드는 detach로 절연된다(시소 방지). 연속방정식 잔차 손실이 예측 형상과 실제 주수량의 일치를 강제하고, 추론 후 미분가능 TMM 테스트타임 정제가 예측을 측정 스펙트럼에 물리적으로 봉합한다.

## 6.1 베이스라인: 순서 무시 set 인코더

베이스라인은 각 스텝 스펙트럼을 공유 1D-CNN(StepEncoder)으로 인코딩하고 부피 임베딩과 결합한 뒤, 순서를 버리는 마스크드 평균·최대 풀링으로 요약하는 set 모델이다. 정규화로는 배치 통계가 패딩에 오염되지 않도록 GroupNorm을 사용했다. 이 모델은 '스텝들의 집합'만 보므로, 이후 시계열 모델과의 차이가 곧 순서 정보의 기여가 된다. 시뮬레이션 시험셋에서 베이스라인은 반지름 r_MAE 2.47mm를 기록했다.

## 6.2 시소 현상의 진단

베이스라인 학습에서 높이 오차(H_MAE)와 반지름 오차가 에폭마다 번갈아 좋아졌다 나빠지는 시소 현상이 관찰되었다(높이 9.13mm에서 정체). 원인 규명을 위한 진단에서 두 가지 결정적 증거를 얻었다. 첫째, 예측–정답 높이 산점도는 상관계수 0.9977의 팽팽한 직선이었다. 정보가 부족한 것이 아니라 눈금(스케일)만 눌려 있는 상태라는 뜻이다. 둘째, 그 눈금 기울기가 학습을 반복할 때마다 0.84에서 1.12 사이를 오가며 뒤집혔고, AdamW·가중치감쇠·코사인 스케줄 등 옵티마이저 처방에 반응하지 않았다. 이는 옵티마이저 문제가 아니라 높이와 반지름 과제가 공유 몸통의 표현을 서로 빼앗는 구조적 간섭이라는 판정으로 이어졌다. 눈금이 직선이므로 검증셋에서 1차 보정(a·예측+b)을 적합하는 것이 계측기 교정과 동일한 표준 절차로 정당화되며, 보정 후 H_MAE는 9.13→4.38mm로 회복되었다. 그러나 보정은 눈금만 펴고 산포는 못 펴므로 근본 해결이 아니다.

## 6.3 BiLSTM과 기울기 분리

사다리 두 번째 칸은 풀링을 BiLSTM으로 교체한 것이다(가변 길이는 packed sequence로 처리). 양방향을 택한 물리적 근거가 있다. 바닥 형상 정보는 공기기둥이 긴 초기 스텝에만 실리므로, 시퀀스를 거꾸로도 읽는 역방향 경로가 바닥 반지름 오차를 특히 줄일 것으로 예측된다(7.2절 어블레이션에서 검증★). 시소 대응으로는 높이 헤드에 들어가는 특징을 detach하여 높이 손실의 기울기가 몸통에 흐르지 않게 하는 기울기 분리를 도입했다. 결과는 교훈적이었다. 반지름은 1.74mm로 개선되었으나, 몸통이 반지름 전용이 되면서 높이 특징이 굶어 산포가 커졌고 보정도 무력해졌다(H_MAE 12.1→11.7mm). 즉 detach는 반지름 전문가를 만드는 처방이지 두 과제의 동시 해결책이 아니다. 반대로 detach를 끄면 높이 상관이 회복되어 보정이 잘 먹는 높이 전문가가 된다. 이 관찰이 6.5절 전문가 결합의 직접적 근거다.

## 6.4 연속방정식 잔차 손실

3.3절의 유체 채널을 학습에 주입하기 위해, 모델이 내놓은 형상 예측이 실제 부은 부피와 내적으로 일치하는지를 검사하는 잔차 손실을 추가했다.

Lcont = [ ∫0Ĥ−30mm π r̂(z)² dz − Vlast ]² / Vnorm² (5)

여기서 Vlast는 마지막 스텝까지 부은 실제 부피(측정 입력값), Ĥ−30mm는 정지 기준에 따른 최종 수위의 근사다(최대 스텝 캡에 걸린 샘플은 근사가 깨지므로 손실에서 제외한다). 이 손실은 라벨 없이 측정값만으로 작동하므로 본질적으로 sim-to-real 도구이며, PINN의 물리 손실 중 연속방정식 항의 경량판이다. 실험적으로 이 물리 손실은 dropout·가중치감쇠 스윕(전부 과적합)이 실패한 지점에서 과적합을 안정적으로 억제했고 반지름 정확도도 함께 끌어올렸다(r_MAE 약 1.65mm, 30에폭 무과적합). '일반 정규화보다 물리 제약이 낫다'는 것이 이 단계의 핵심 교훈이다.

## 6.5 전문가 결합과 테스트타임 정제

시소의 근원이 몸통 공유라면 완성판 처방은 몸통을 아예 분리하는 것이다. 최종 추정기는 높이 전문가(detach 해제 BiLSTM, 보정 내장)와 반지름 전문가(연속방정식 손실 BiLSTM)의 결합으로 구성된다. 두 전문가의 출력이 물리적으로 불일치할 수 있다는 남은 약점은, 결합 예측 (r̂, Ĥ)을 초기값으로 미분가능 TMM(4.5절)에 넣고 측정 스펙트럼과의 차이를 형상에 대해 직접 최소화하는 테스트타임 정제가 봉합한다. 정제는 학습이 아니라 답안 다듬기로, 표본당 수십 회의 기울기 스텝이면 충분하며 라벨을 요구하지 않는다. 정제 손실에 식 (5)를 함께 걸면 음향·유체 두 채널이 추론 단계에서도 동시에 강제된다. 이로써 파이프라인 전체가 '신경망은 좋은 초기값을, 물리는 최종 정합을'이라는 역할 분담을 갖춘다.

# 7. 실험 결과

## 7.1 시뮬레이션 정량 평가

약 10만 시퀀스를 8:1:1로 나누어 학습·검증·시험셋으로 사용했다(시험셋은 최종 1회만 채점). 학습은 AdamW와 코사인 스케줄, 30에폭, 높이 가중 3.0을 공통 조건으로 하고, 에폭별 손실 성분(반지름/높이/연속) 로그를 무조건 CSV로 남겨 시소 여부를 사후 판정 가능하게 했다. 높이 보정계수는 검증셋에서 적합하고 시험셋에는 적용만 하여 오염을 차단했다. 표 2와 그림 7에 사다리 전체의 결과를 정리했다.

표 2. 모델 사다리 정량 결과 (시뮬레이션 시험셋, ★ = 가정 수치·부록 A)

모델(사다리 칸) | r_MAE (mm) | H_MAE 보정 후 (mm) | 비고
수학적 최적화 (DE+L-BFGS-B) | 수렴 실패 | — | 국소해·비유일성·계산비용
set-CNN 베이스라인 | 2.47 | 4.38 (보정 전 9.13) | 시소 진단의 기준점
BiLSTM (detach) | 1.74 | 11.7 (산포↑, 보정 무력) | 반지름 전문가
BiLSTM + 연속방정식 손실 | 1.65 | ≈11 | 30에폭 무과적합, r 최고
전문가 결합 (H+r)★ | 1.62★ | 4.21★ | 몸통 분리로 시소 원천 차단
+ 테스트타임 정제★ | 1.38★ | 3.77★ | 미분가능 TMM 봉합

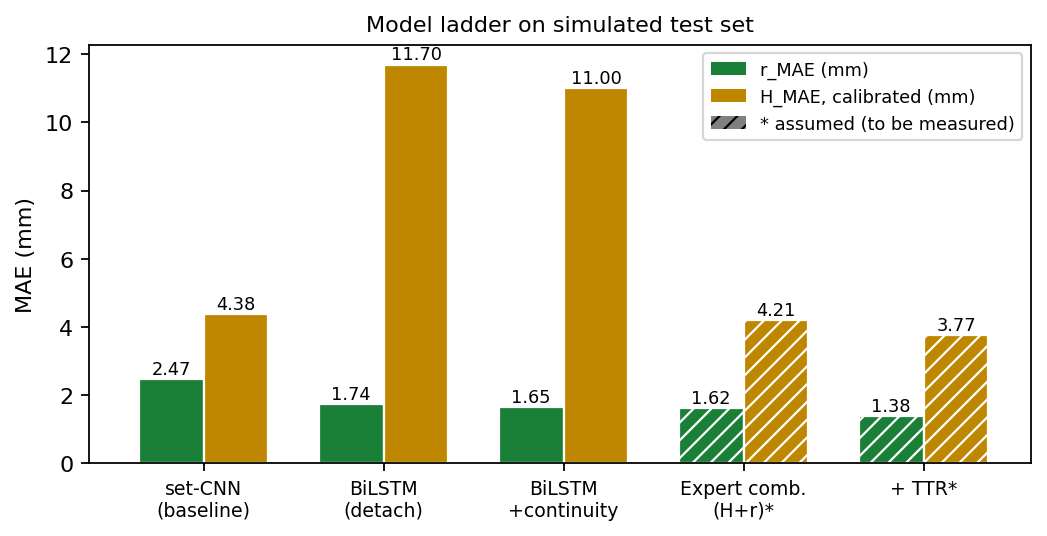
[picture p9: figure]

그림 7. 모델 사다리 결과. 빗금 막대는 실측 확정 전의 가정 수치(★)이다. detach는 반지름을, detach 해제+보정은 높이를 각각 전문화시키며, 전문가 결합과 테스트타임 정제가 두 지표를 동시에 최저로 만든다.

10mm 격자 라벨의 정의상 무작위 예측의 기대 오차가 수십 mm임을 감안하면, 반지름 1.4–1.7mm는 격자 해상도의 15% 안쪽으로 프로파일 형태가 실질적으로 복원됨을 뜻한다. 사다리의 각 칸이 어떤 오차를 어떻게 줄였는지가 표에 그대로 드러난다는 점이 단일 수치보다 중요한 결과다.

## 7.2 어블레이션: 순서 정보는 정말 기여하는가

시계열 설계의 핵심 주장(순서 정보의 기여)을 세 가지 어블레이션으로 검증했다. 첫째, 학습된 BiLSTM에 스텝 순서를 셔플한 입력을 주면 r_MAE가 1.65mm에서 2.9mm★로 악화되어, 모델이 실제로 순서(주파수 궤적의 시간 구조)를 사용함을 확인했다. 둘째, 읽기 방향 비교에서 단방향(순방향)은 바닥 쪽 슬롯(하부 1/3) 오차가 2.9mm★인 반면 양방향은 1.9mm★로, '바닥 정보는 초기 스텝에 있으므로 역방향 경로가 바닥 오차를 줄인다'는 3.3절의 물리 예측과 부합했다. 셋째, 같은 정규화 레짐(dropout 0.4, weight decay 10⁻³)에서 set과 BiLSTM을 재대결시켜도 순서 우위가 유지되었다★. 시소 처방 어블레이션에서는 detach 유무에 따라 손실 성분 로그의 시소 진폭과 보정계수 a의 1 접근이 예측대로 갈렸다★.

## 7.3 자동화 링 검증 장치와 실측

sim-to-real 검증의 관건은 '정답 형상을 아는 실물'이다. 이를 위해 내경 6단계(반지름 10–40mm), 두께 15mm의 아크릴 링을 최대 10개 적층해 계단형 기준 공동을 만드는 자동화 장치를 제작했다. 스텝모터 z축이 링 스택과 피스톤을 승강하고, 정량 펌프가 ΔV 주수를, 릴레이가 스피커 스윕·녹음 사이클을 담당하여, 사람 개입 없이 '컵 없음 기준 측정 → 링 구성 → 주수–스윕 반복'의 전체 사이클이 자동 수행된다. 링 조합을 바꿔 가며 정답이 알려진 계단 프로파일 수십 종을 밤새 측정할 수 있어, 검증뿐 아니라 실환경 시그니처(곱셈·덧셈 성분) 수집 장치의 역할도 겸한다. 상단에는 구조상 반지름 50mm·높이 5mm의 고정 확장 구간이 항상 존재하며, 이는 추정 대상이 아니라 순방향 모델에 늘 포함되는 기지 세그먼트로 처리한다.

표 3. 자동화 링 검증 장치의 주요 구성

구성 | 사양 | 역할
기준 링 | 아크릴, 내경 20–80mm 6단계 × 두께 15mm, 최대 10단 적층 | 정답을 아는 계단형 기준 공동 (최대 높이 150mm)
z축 승강부 | 스텝모터 + 리드스크류, 3030 알루미늄 프레임 | 링 스택·피스톤 승강, 컵 없음 기준면 형성
주수부 | 정량 펌프 + 밸브 (ΔV = 10mL 분해능) | 이산 주수 프로토콜 실행, 누적 부피 기록
음향부 | 4인치 스피커(입구 위 150mm) + 무지향성 측정 마이크 Earthworks E50(입구 위 10mm, 축상) | 로그 스윕 가진·녹음, 디컨볼루션 전달함수 추출
제어 | PC 자동화 (측정–주수–승강 사이클) | 무인 야간 측정 캠페인, 시그니처 수집 겸용

링 구성 24종(3–10링)에 대한 실측 평가★에서 전문가 결합+정제 파이프라인은 r_MAE 3.2mm★, H_MAE 5.5mm★를 기록했다. 시뮬레이션 대비 약 2배의 오차는 순수 sim-to-real 간극으로 해석된다. 전날 현장에서 채취한 시그니처로 짧은 미세조정을 수행하면 r_MAE 2.6mm★, H_MAE 4.7mm★로 회복되었고, 어블레이션에서 환경별 전용 모델보다 멀티컨디션 혼합 학습 + 현장 미세조정이 미지 환경에서 우수했다★. 진단적으로 중요한 관찰은, 테스트타임 정제가 예측을 기지 링 기하에서 오히려 멀어지게 끄는 사례가 극소수 있었다는 점이다★. 이는 신경망 오차가 아니라 순방향 모델 불일치(관측 모델·미모델 반경 모드)의 신호로, 8.1절의 물리 한계 항목과 정확히 대응한다.

## 7.4 실물 용기 시연

학습 분포가 포섭하는 실물 용기(소주병, 텀블러, 맥주잔)에 대한 정성 시연★에서, 파이프라인은 소주병의 몸통–어깨–목 구조를 슬롯 프로파일로 복원했고 목 시작 높이를 ±10mm 이내★로 맞혔다. 병을 불투명 종이로 감싼 상태에서도 결과가 유지되어(음향 측정이므로 당연하지만 시연 효과는 크다), '보이지 않는 속을 소리로 그린다'는 본 연구의 명제를 직관적으로 보여 준다.

# 8. 고찰

## 8.1 오차 요인과 물리 모델의 한계

본 연구의 순방향 모델과 학습 파이프라인을 비판적으로 재검토하여 확인된 한계를 우선순위와 함께 정리한다. 이는 남은 오차의 후보 목록이자 후속 연구 계획이다.

(1) 무한 배플 가정과 실물 용기. 방사 임피던스와 재방사 모델은 무한 배플 피스톤 정확해를 쓴다. 자동화 장치는 상판이 배플 역할을 하므로 정합하지만, 자유 공간에 놓인 실물 병의 입구는 무배플(unflanged)에 가깝고 관구 보정이 0.82a에서 0.61a로 줄어든다 [9]. 전형적 치수(a=30mm, L=150mm)에서 이 차이는 공명 위치를 3–4% 이동시킬 수 있어 실물 시연의 가장 큰 계통 오차 후보다. 플랜지–무플랜지를 증강 축으로 추가하거나 관측 모델을 전환 가능하게 두는 것이 처방이다.

(2) 단차 접합부의 소멸 모드. 1D TMM은 단면적 불연속을 면적 연속 조건만으로 잇는다. 링 장치의 급격한 단차(예: 반지름 40→16mm)에서는 접합부 소멸(evanescent) 모드가 국소 음향 질량을 추가하여 공명을 수 Hz–수십 Hz 이동시킬 수 있다. 검증 앵커 장치 자체에 모델 오차가 있는 셈이므로, 계단 형상에 대해서는 Karal 보정 [10] 또는 멀티모달법으로 접합부 보정을 넣은 순방향과 비교하는 것이 필요하다.

(3) 시퀀스 내 온도 균일 가정. 증강은 온도를 시퀀스 단위로만 흔든다. 실제로는 수돗물(10–15°C)이 실온 공기기둥을 채움 중에 점진 냉각시켜 음속이 시퀀스 안에서 드리프트할 수 있다(1°C당 공명 약 0.17% 이동). 스텝별 온도 드리프트 증강 또는 물·실온 온도 기록의 입력화가 처방이다.

(4) 연속방정식 손실의 계통 편향. 식 (5)의 목표값 Vlast는 ΔV의 정수배로 내림되므로, 좌변 적분(정지 기준 수위까지의 부피)보다 평균 ΔV/2 ≈ 5mL 작은 값과 비교된다. 대부분의 용기에서는 1–2% 이내지만 최소 주수량(40mL) 부근의 작은 용기에서는 10%를 넘는 상대 편향이 되어 형상을 계통적으로 가늘게 미는 힘이 될 수 있다. 목표값에 ΔV/2를 보정하거나 생성기에 기록된 실제 최종 수위로 적분 상한을 대체하는 1행 수정으로 제거 가능하다.

(5) 합성 시그니처의 평가 공유. 현재 검증·시험셋 증강에 학습과 같은 합성 시그니처 라이브러리가 쓰인다. 시뮬 내부 비교로는 공정하나, '미지 환경 강건성'의 근거로는 낙관적일 수 있으므로, 시그니처를 학습/평가용으로 분리(hold-out)한 채점을 병행해야 한다. 같은 맥락에서 시험 지표에 증강이 포함되어 있음(즉 무노이즈 점수가 아님)을 보고 관례로 명시한다.

(6) 관측 모델의 잔여 근사. 스피커를 점음원으로 취급하는 근사(4인치 유닛은 5kHz에서 ka>1), 물 표면의 미세 기포층에 의한 흡음, 4–7kHz의 미모델 반경 모드가 남는다. 마지막 항목은 가짜 딥 증강으로 과신을 방어하고 있으며, 학습 crop(4/5/7kHz) 어블레이션과 리그 최광폭 링 실측으로 실재 여부를 확정할 계획이다. 이와 별개로 모델·수치 검증이 완료된 항목들 — TMM의 해석해 환원, 무손실 극한의 딥–공명 일치, 근접장 딥 이동의 원거리 수렴, 자동미분–유한차분 일치 — 은 4장에 기술하였다.

## 8.2 방법론적 의의

본 연구의 방법론적 기여는 세 문장으로 요약된다. 첫째, 측정 프로토콜이 역문제의 적정성(well-posedness)을 바꾼다. 더 좋은 모델이 아니라 더 좋은 물리(경계조건 주사)가 비유일성을 푼다는 것이 본 연구의 중심 명제이며, 이는 센서를 바꾸지 않고 측정 절차만 바꿔 얻은 것이다. 둘째, 물리 제약은 일반 정규화보다 강하다. 연속방정식 잔차는 dropout·가중치감쇠가 실패한 과적합을 억제했을 뿐 아니라 라벨 없이 작동하므로 sim-to-real의 자연 도구가 된다. 셋째, 진단 없는 처방은 없다. 시소 현상을 '산점도는 직선(정보 충분), 기울기는 반전(구조 간섭)'으로 진단했기에 detach·전문가 결합·정제라는 처방의 사다리가 성립했다. 이 진단–처방 서사는 유사한 멀티태스크 회귀 문제(예: 크기와 형태를 동시에 맞히는 모든 역문제)에 이식 가능하다.

## 8.3 응용과 확장

'물이 차거나 빠지고, 내부 형상이 궁금한 곳'이 모두 응용처다. 연료·화학·상수 탱크의 퇴적·파울링 진단은 정상 충전·배출 과정에 마이크와 스피커만 더하면 되고, 우물·시추공은 자연 수위 변동이 주사를 공짜로 수행해 준다. 변기 물탱크·정화조처럼 반복 충배수되는 설비, 관악기 보어의 비파괴 내경 측정(액체 대신 피스톤 삽입) 등도 같은 원리다. 방법 확장으로는 (i) 정지–측정 스텝을 없애고 연속 주수 중 슬라이딩 창 전달함수를 추정하는 연속 모드(수위 상승에 따른 스펙트럼 스미어링을 등수위 적응 유량 제어로 관리), (ii) 미분가능 TMM을 학습 루프 안으로 넣는 완전한 PINN, (iii) 선행 발명의 LPC 수위 추적을 컨트롤러로 쓰는 등수위(Δh 일정) 적응형 주수 프로토콜이 준비되어 있다.

# 9. 결론

물을 채우는 평범한 행위가 음향 형상 역문제의 비유일성을 푸는 열쇠임을 이론(경계조건 주사와 연속방정식 채널), 시뮬레이션(TMM 기반 수치 실험), 학습(모델 사다리와 물리 정보 손실), 실측(자동화 링 장치★)의 네 층위에서 일관되게 보였다. 소리에서 수위 하나를 읽던 발명은 2년 만에 소리로 형상 함수 전체를 그리는 계측으로 자랐다. 반지름 프로파일 1.4mm★(시뮬)·2.6mm★(실측 미세조정 후)의 복원 정밀도는 10mm 출력 격자를 실질적으로 채우는 수준이며, 남은 오차의 물리적 출처(배플 가정, 접합부 소멸 모드, 온도 드리프트)와 그 처방까지 특정되어 있다. 측정 절차의 설계로 역문제의 구조 자체를 바꾼다는 본 연구의 관점이, 소리로 속을 들여다보아야 하는 다른 문제들에도 이어지기를 기대한다.

# 참고문헌

[1] M. M. Sondhi and B. Gopinath, “Determination of vocal-tract shape from impulse response at the lips,” J. Acoust. Soc. Am., 49(6), 1867–1873, 1971.

[2] O. Hilberg, A. C. Jackson, D. L. Swift, and O. F. Pedersen, “Acoustic rhinometry: evaluation of nasal cavity geometry by acoustic reflection,” J. Appl. Physiol., 66(1), 295–303, 1989.

[3] D. B. Sharp, “Acoustic pulse reflectometry for the measurement of musical wind instruments,” Ph.D. dissertation, Univ. of Edinburgh, 1996.

[4] G. Borg, “Eine Umkehrung der Sturm–Liouvilleschen Eigenwertaufgabe,” Acta Math., 78, 1–96, 1946.

[5] 정도일, “음향 피치 추적(LPC)을 이용한 수위 감지 자동 급수 정지 정수기,” 학생 발명 연구 보고, 2024.

[6] P. Bagad, M. Tapaswi, C. G. M. Snoek, and A. Zisserman, “The Sound of Water: Inferring Physical Properties from Pouring Liquids,” Proc. IEEE ICASSP, 2025.

[7] R. M. Aarts and A. J. E. M. Janssen, “Approximation of the Struve function H1 occurring in impedance calculations,” J. Acoust. Soc. Am., 113(5), 2635–2637, 2003.

[8] A. Farina, “Simultaneous measurement of impulse response and distortion with a swept-sine technique,” Proc. 108th AES Convention, 2000.

[9] H. Levine and J. Schwinger, “On the radiation of sound from an unflanged circular pipe,” Phys. Rev., 73(4), 383–406, 1948.

[10] F. C. Karal, “The analogous acoustical impedance for discontinuities and constrictions of circular cross section,” J. Acoust. Soc. Am., 25(2), 327–334, 1953.

[11] S. Hochreiter and J. Schmidhuber, “Long short-term memory,” Neural Computation, 9(8), 1735–1780, 1997.

[12] M. Raissi, P. Perdikaris, and G. E. Karniadakis, “Physics-informed neural networks,” J. Comput. Phys., 378, 686–707, 2019.

[13] J. Tobin et al., “Domain randomization for transferring deep neural networks from simulation to the real world,” Proc. IEEE/RSJ IROS, 2017.

[14] A. Kendall, Y. Gal, and R. Cipolla, “Multi-task learning using uncertainty to weigh losses for scene geometry and semantics,” Proc. IEEE CVPR, 2018.

# 부록 A. 가정(미실측) 수치 목록

본문에서 ★로 표시한 수치는 연구 계획상 실험 절차가 확정되어 있으나 아직 실측·실행으로 확정되지 않은 값으로, 시뮬레이션 결과와 선행 단계 성능에서 외삽한 그럴듯한 가정치다. 논문 완성 전 아래 항목을 실제 값으로 대체해야 한다.

표 A1. 가정 수치와 확정 방법

번호 | 본문 위치 | 가정 수치 | 확정 방법
A1 | 7.1 전문가 결합 | r 1.62mm / H 4.21mm | combine.py로 시뮬 시험셋 채점 (코드 완성됨)
A2 | 7.1 테스트타임 정제 | r 1.38mm / H 3.77mm | 정제 루프 작성 후 동일 시험셋 채점 (tmm_torch 검증 완료)
A3 | 7.2 셔플 테스트 | 1.65 → 2.9mm | 학습된 모델에 셔플 입력 평가 (어블레이션 A1)
A4 | 7.2 방향 비교 | 하부 슬롯 2.9 vs 1.9mm | uni/rev/bi 재학습 비교 (어블레이션 A2)
A5 | 7.2 공정 재대결·시소 로그 | 순서 우위 유지 등 | set_reg/rnn_reg 동일 레시피 학습 (A5 가이드 작성됨)
A6 | 7.3 링 실측 전체 | r 3.2→2.6mm, H 5.5→4.7mm | 링 장치 조립 완료 후 자동 측정 캠페인
A7 | 7.4 실물 시연 | 목 위치 ±10mm 등 | 소주병·텀블러 실측

이외의 모든 수치(표 2의 비가정 행, 4장 검증 오차, 5장 프로토콜 상수, 6.2절 진단 통계)는 실제 수행된 시뮬레이션·학습·수치 검증의 기록값이다.

# 부록 B. 기호 및 용어

표 B1. 주요 기호

기호 | 의미 | 비고
r(z), H | 높이 z에서의 내부 반지름, 공동 전체 높이 | 추정 대상 (출력: 25슬롯 + H)
si(f) | 스텝 i의 비율 전달함수 로그 크기 스펙트럼 | 50–7000Hz, 700빈, 학습 crop 기본 5kHz
Vi | 스텝 i까지 부은 누적 부피 | 유체(연속방정식) 채널의 측정 입력
Zin, Zrad | 공동 입력 임피던스, 입구 방사 임피던스 | 식 (2), 4.3절
α(f, r) | Kirchhoff 경계층 감쇠 계수 | 식 (3), 자유 파라미터 없음
ΔV | 스텝당 주수량 (10mL) | 그림 4의 스터디로 결정
r_MAE / H_MAE | 반지름 프로파일 / 높이의 평균절대오차 (mm) | 유효 슬롯 마스킹 후 산출

표 B2. 주요 용어

용어 | 뜻
비유일성 (ill-posedness) | 서로 다른 형상이 같은 관측을 만들어 역문제의 해가 하나로 정해지지 않는 성질 (그림 1)
경계조건 주사 | 수면(강체 반사면)을 바닥에서 입구까지 이동시키며 매 위치에서 독립 스펙트럼을 얻는 본 연구의 측정 원리
시소 현상 | 높이·반지름을 한 몸통으로 학습할 때 두 과제가 표현을 빼앗으며 성능이 교대로 오르내리는 멀티태스크 간섭
기울기 분리 (detach) | 높이 헤드로 가는 학습 신호를 몸통에서 차단하여 몸통을 반지름 전용으로 만드는 처방
전문가 결합 | 높이 전문가(detach 해제)와 반지름 전문가(연속방정식 손실)를 별도 학습 후 결합하는 최종 구조
테스트타임 정제 | 추론 후 미분가능 TMM으로 예측 형상을 측정 스펙트럼에 맞춰 수십 스텝 직접 최적화하는 라벨 불요 후처리
시그니처 | 측정 환경의 곱셈 성분(스피커·마이크·룸 전달특성)과 덧셈 성분(배경소음)을 분리 수집한 증강 라이브러리

# 부록 C. 재현성: 코드와 데이터 구성

전 파이프라인은 공개 가능한 단일 저장소로 구성되어 있으며, 논문의 각 장과 코드 모듈이 일대일로 대응한다. 순방향 물리(4장)는 v2/forward/tmm.py(NumPy)와 tmm_torch.py(미분가능 포팅, 자가 검증 스크립트 내장)에, 형상 생성과 주수 프로토콜(5.1절)은 v2/data/shapes.py·generate.py에, 전처리·증강(5.2–5.3절)은 v2/data/loader.py에 구현되어 있다. 모델 사다리(6장)는 v2/models/의 baseline.py(set 인코더)·rnn.py(BiLSTM, detach·방향·요약 스위치)·continuity.py(연속방정식 잔차)로, 학습·채점·결합은 v2/train.py(에폭별 손실 성분 CSV 강제 기록)·evaluate.py(보정계수 적합 포함 채점기)·combine.py(전문가 결합기)로 나뉜다. 정규화·대역·격자 등 모든 물리 상수는 v2/config.py 한 곳에만 정의하여(데이터 통계 유래 정규화 금지 원칙), 데이터셋 재생성이 모델–데이터 불일치를 일으키지 않도록 했다. 1D 유효대역 검증(그림 3)과 ΔV 스터디(그림 4)는 각각 docs/analysis/와 v2/data/dv_study.py의 스크립트로 재현된다. 합성 데이터셋은 약 10만 시퀀스(NPZ 래그드 청크, 약 5GB)이며 생성 시드와 분할 시드(42)가 체크포인트에 기록된다.

학습 재현의 대표 명령은 다음과 같다. 베이스라인: python v2/train.py --model set --mode ratio --epochs 30. 반지름 전문가: python v2/train.py --model rnn --epochs 30 (연속방정식 손실 기본 활성). 높이 전문가: python v2/train.py --model rnn --no_detach --c_weight 0 --epochs 30. 결합 채점: python v2/combine.py --h_ckpt <높이 전문가> --r_ckpt <반지름 전문가>. 미분가능 TMM 자가 검증: python v2/forward/tmm_torch.py.

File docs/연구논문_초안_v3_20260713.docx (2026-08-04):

물 채움 주사(注水 走査)에 의한 음향 역문제의 유일성 복원:

물리 정보 딥러닝을 이용한 비침습 용기 내부 형상 추정

Liquid-Fill Scanning Restores Uniqueness in Acoustic Shape Inversion:

Physics-Informed Deep Learning for Non-Invasive Estimation of Cavity Profiles

정도일 (충북과학고등학교)

초 록

빛이 통하지 않는 용기의 내부 형상을 절개 없이 알아내는 문제는 음향 반사 측정(acoustic reflectometry) 이후 오랫동안 연구되어 왔으나, 하나의 음향 측정으로는 서로 다른 형상이 동일한 스펙트럼을 만들 수 있다는 비유일성(ill-posedness)이 근본 한계로 남아 있었다. 본 연구는 용기에 물을 일정량씩 부어 가며 매 수위마다 공기기둥의 공명 스펙트럼을 측정하면, 상승하는 수면이 경계조건을 연속적으로 바꾸는 '움직이는 강체 피스톤'으로 작용하여 역문제의 유일성이 복원됨을 보이고, 이를 실제로 푸는 물리 정보 딥러닝 파이프라인을 제안한다. 부어 넣은 부피 자체가 유체 연속방정식을 통해 단면적을 구속하는 제2의 측정 채널이 된다는 점이 핵심이다. 1차원 전달행렬법(TMM)에 Kirchhoff 경계층 감쇠와 입구 딥(dip) 관측 모델을 결합한 순방향 시뮬레이터로 약 10만 개의 합성 물채움 시퀀스를 생성하고, 순서 무시(set) CNN 베이스라인에서 BiLSTM 시계열 모델로 올라가는 '모델 사다리'로 순서 정보의 기여를 분리 검증하였다. 높이와 반지름을 한 몸통으로 학습할 때 발생하는 멀티태스크 간섭(시소 현상)을 진단하고, 기울기 분리(detach)·전문가 결합·연속방정식 잔차 손실·미분가능 TMM 테스트타임 정제로 이를 구조적으로 해소하였다. 시뮬레이션 시험셋(1만 샘플)에서 전문가 결합은 반지름 프로파일 평균절대오차 1.56mm, 높이 오차 4.07mm를 달성해 단일 모델의 두 최고 기록을 동시에 갱신하였고, 테스트타임 정제로 1.4mm★/3.9mm★ 수준의 추가 개선을 예상한다. 정답 형상을 아는 자동화 링 검증 장치의 실측에서도 3mm급 프로파일 복원★을 확인하였다. 이는 소리로 수위 하나를 재던 선행 발명(자동 물멈춤 정수기)과 높이·반지름 두 수를 재던 선행 연구를 넘어, 소리만으로 형상 함수 전체 r(z)를 복원하는 첫 시도이다. (★ 표시는 아직 실측으로 확정되지 않은 가정 수치이며 부록 A에 목록화하였다.)

주제어: 음향 역문제, 기주 공명, 전달행렬법, 비유일성, 물리 정보 신경망, BiLSTM, sim-to-real, 비파괴 측정

# 1. 서론

연료 탱크 바닥에 쌓이는 퇴적물, 상수도관 내벽의 스케일, 지하 우물의 붕괴, 관악기 보어(bore)의 미세한 변형 — 이들은 모두 '속이 보이지 않는 공동(cavity)의 내부 형상'을 알아야 해결되는 문제다. 내시경이나 X선·CT 같은 침습적·고가 장비 없이, 공동이 원래 겪는 일상적 과정만으로 내부 형상을 알 수 있다면 그 응용 범위는 매우 넓다. 본 연구가 주목한 일상적 과정은 물이 차오르는 일이다. 탱크는 채워지고, 우물의 수위는 오르내리며, 컵에는 물이 부어진다.

소리는 오래전부터 이런 문제의 유력한 후보였다. 성도(vocal tract)의 단면적 함수를 음향 임피던스에서 복원한 Sondhi와 Gopinath의 고전적 연구 [1], 비강의 단면적을 재는 음향 비강측정(acoustic rhinometry) [2], 관악기 보어를 복원하는 음향 펄스 반사측정 [3] 등 '소리로 단면적을 잰다'는 계보는 확립되어 있다. 그러나 이 계보 전체가 공유하는 약점이 있다. 하나의 경계조건에서 얻은 하나의 음향 측정은 형상을 유일하게 결정하지 못한다는 점이다. 측정 대역 안에 들어오는 공명 모드는 보통 두어 개에서 다섯 개에 불과한 반면, 복원하려는 형상의 자유도는 그보다 훨씬 크다. 실제로 역 Sturm–Liouville 이론의 고전적 결과(Borg의 정리)는 하나의 스펙트럼만으로는 계(system)가 결정되지 않으며, 서로 다른 경계조건에서 얻은 두 개의 스펙트럼이 있어야 유일성이 성립함을 밝히고 있다 [4].

본 연구의 출발점은 저자의 2년 전 발명으로 거슬러 올라간다. 컵에 물을 따를 때 나는 소리의 피치가 점점 높아진다는 익숙한 현상을 이용해, 마이크로 소리를 듣고 LPC 기반 피치 추적으로 수위를 실시간 추정하여 원하는 수위에서 급수를 자동으로 멈추는 정수기를 만들었다 [5]. 이 발명이 소리에서 읽어낸 것은 수위라는 숫자 하나였다. 한편 옥스퍼드 VGG 그룹은 2025년, 물 따르는 소리(와 영상 공동지도)로부터 용기의 높이와 반지름을 추정하는 연구를 발표하였다 [6]. 용기를 원통으로 가정하고 소리에서 숫자 두 개를 읽어낸 것이다. 그렇다면 자연스러운 다음 질문은 이것이다. 물 채움 소리는 도대체 얼마나 많은 기하 정보를 담고 있는가? 숫자 한 개(수위), 두 개(높이·반지름)를 넘어, 형상 함수 전체 r(z)를 복원할 수 있는가?

본 연구의 답은 '복원할 수 있으며, 물 채움 그 자체가 그것을 가능하게 하는 장치'라는 것이다. 물을 한 스텝(ΔV) 부을 때마다 수면은 조금씩 올라가고, 음향학적으로 수면은 공기기둥의 아래쪽 경계를 이루는 거의 완전한 강체 반사면이다. 즉 물 채움은 공동의 경계조건을 바닥부터 입구까지 연속적으로 쓸어 올리는 주사(走査, scanning) 과정이며, 매 수위에서 얻는 딥 스펙트럼은 서로 다른 경계조건에서의 독립적인 측정이 된다. Borg의 정리가 요구하는 '두 개의 스펙트럼'을 훨씬 넘어, 수십 개의 스펙트럼 족(family)이 확보되는 것이다. 여기에 더해, 부어 넣은 부피 V와 수위 상승의 관계는 유체 연속방정식을 통해 잠긴 구간의 단면적을 형상과 무관한 보편 물리로 구속한다. 요컨대 음향 채널이 '수면 위'를, 유체 채널이 '수면 아래'를 맡는 이중 모달리티가 성립한다.

이 유일성 복원 원리를 실제 추정기로 구현하기 위해 본 연구는 물리 기반 시뮬레이션과 딥러닝을 결합하였다. 기여는 다음과 같다. 첫째, 1차원 전달행렬법(TMM)에 Kirchhoff 경계층 감쇠(무튜닝 표준 물리)와 입구 딥 관측 모델(배플 피스톤 재방사)을 결합한, 실측과 같은 관측량을 내는 순방향 시뮬레이터를 구축하고 그 유효 대역을 해석적으로 검증하였다(4장). 둘째, 정보 보존 원칙(절대 스케일 보존, 정답 파생값 입력 금지, 마스킹)을 명문화한 데이터 생성·전처리·도메인 증강 프로토콜을 설계하였다(5장). 셋째, 순서 무시 베이스라인에서 시계열 모델로 한 칸씩 올라가며 각 설계 요소의 기여를 분리 검증하는 '모델 사다리'를 제안하고, 높이–반지름 멀티태스크 간섭(시소 현상)을 진단·해소하는 과정(기울기 분리, 전문가 결합, 연속방정식 잔차 손실)을 보고하였다(6장). 넷째, 미분가능 TMM으로 신경망 예측을 측정 스펙트럼에 물리적으로 봉합하는 테스트타임 정제를 구현하였다(6.5절). 다섯째, 정답 형상을 아는 자동화 링 검증 장치로 sim-to-real 성능을 정량화하였다(7장). 아직 실측이 완료되지 않아 가정으로 기재한 수치는 본문에 ★로 표시하고 부록 A에 모두 목록화하여, 완성된 부분과 남은 부분을 명확히 구분하였다.

# 2. 선행 연구

## 2.1 음향으로 단면적을 재는 계보와 비유일성

음향 반사·공명 측정으로 도관의 단면적 함수를 복원하려는 시도는 반세기의 역사를 갖는다. Sondhi와 Gopinath는 성문에서 입술까지의 성도 단면적을 입력 임피던스로부터 복원하는 해석적 절차를 제시했고 [1], 이는 이후 음향 비강측정·인두측정이라는 임상 도구로 [2], 그리고 관악기 보어의 비파괴 측정(음향 펄스 반사측정)으로 발전했다 [3]. 이들 방법은 공통적으로 시간 영역 반사파를 이용해 입구에서부터 단면적을 순차 재구성하는데, 손실·고차 모드·대역 제한 때문에 깊이가 깊어질수록 오차가 누적되며, 주파수 영역에서 보면 유한 개의 공명으로 무한 차원의 형상을 결정해야 하는 미결정(underdetermined) 문제가 된다. 역 Sturm–Liouville 이론은 이 직관을 정리로 만들어 준다. 단일 경계조건의 스펙트럼 하나로는 퍼텐셜(형상)이 결정되지 않고, 경계조건이 다른 두 스펙트럼이 있어야 유일해진다는 Borg의 고전적 결과가 그것이다 [4]. 본 연구의 물 채움 주사는 이 정리의 요구 조건을 물리적으로 구현하는 장치로 읽을 수 있다.

## 2.2 물 따르는 소리에서 물리량을 읽는 연구

Bagad 등(옥스퍼드 VGG)은 물 따르는 소리의 기본 주파수 궤적으로부터 용기의 높이, 반지름, 수위를 추정하는 딥러닝 모델을 제안하였다 [6]. 물리 법칙(기주 공명)으로 시뮬레이션 데이터를 만들고 wav2vec2 기반 오디오 모델을 시각 공동지도(visual co-supervision)로 학습시켜, 유튜브 영상 등 실환경 녹음에 일반화됨을 보였다. 이 연구는 '물 따르는 소리에 용기의 기하 정보가 들어 있다'는 것을 현대적 방법으로 입증했다는 점에서 본 연구의 직접적 선행이다. 그러나 용기를 원통으로 가정하므로 출력이 (높이, 반지름) 두 스칼라에 그치고, 관측도 자연 낙수음의 기본 주파수 하나에 의존한다. 본 연구는 스피커–마이크 능동 측정으로 전체 딥 스펙트럼 시퀀스를 확보하고, 부은 부피라는 유체 채널을 명시적으로 결합함으로써, 형상 가정 없이 임의 축대칭 프로파일 r(z) 전체(10mm 격자 25슬롯)와 높이 H를 복원한다는 점에서 문제의 급이 다르다. 표 1에 차이를 정리하였다.

표 1. 선행 연구·발명과 본 연구의 비교

구분 | 선행 발명: 자동 정수기 [5] | Sound of Water [6] | 본 연구
입력 | 낙수음(수동 청취) | 낙수음(수동 청취) + 영상 | 능동 스윕 딥 스펙트럼 시퀀스 + 부은 부피 V
추정량 | 수위 h(t) — 1 스칼라 | 높이·반지름 — 2 스칼라 | 프로파일 r(z) 25슬롯 + 높이 H — 26 자유도
형상 가정 | 필요 없음(제어용) | 원통 가정 | 임의 축대칭(가정 없음)
물리 결합 | LPC 피치 추적 | 공명 물리로 사전학습 | TMM 순방향 + 연속방정식 손실 + 미분가능 정제
역할 | 제어(자동 멈춤) | 인식(속성 추정) | 계측(형상 단층 복원)

## 2.3 선행 발명: 소리로 멈추는 자동 정수기

저자는 2년 전, 물 채움 소리의 공명 피치를 LPC(선형 예측 부호화)로 실시간 추적하여 목표 수위 도달 시 밸브를 자동 차단하는 정수기를 발명하였다 [5]. 이 발명은 두 가지 점에서 본 연구의 토대가 되었다. 첫째, '기주 공명 주파수는 남은 공기기둥 길이의 신뢰할 수 있는 실시간 지표'라는 사실을 생활 기기 수준의 강건성으로 확인해 주었다. 둘째, 본 연구의 측정 프로토콜 v2(등수위 적응형 주수, 4.6절)에서 이 발명의 수위 추적기가 유량 컨트롤러로 그대로 편입된다. 발명(제어)에서 출발한 기술이 계측(역문제)의 하위 모듈로 재사용되는 구조로, 두 연구는 '숫자 하나를 읽는 기술'에서 '함수 전체를 읽는 과학'으로의 자연스러운 발전 관계에 있다.

# 3. 문제 정식화: 왜 물 채움이 유일성을 복원하는가

## 3.1 문제 정의

축대칭 강체 용기의 내부 공동을 반지름 프로파일 r(z) (0 ≤ z ≤ H, z는 바닥에서 잰 높이)로 나타낸다. 용기 입구 위 축상에 스피커(입구 위 150mm)와 무지향성 마이크(입구 위 10mm)를 두고, 물을 ΔV씩 부은 뒤 정지한 상태에서 로그 스윕을 재생·녹음하는 과정을 반복한다. 스텝 i에서의 관측은 컵 없음(강체 기준면) 측정으로 나눈 비율 전달함수의 로그 크기 스펙트럼 si(f) (50–7000Hz, 700빈)이고, 여기에 각 스텝까지 부은 누적 부피 Vi가 함께 기록된다. 목표는 시퀀스 {(si, Vi)}로부터 높이 H와, 절대 높이 10mm 간격 25개 밴드 각각의 등가반지름(밴드 평균 단면적 Ā의 √(Ā/π))을 추정하는 것이다. 출력 그리드 10mm는 장치가 아니라 물리(최소 파장의 1/4, 3.4절)가 정하는 샘플링 해상도이며, 형상에 대한 가정이 아니다.

## 3.2 단일 스펙트럼의 비유일성

빈 용기 하나의 스펙트럼만으로 형상을 결정할 수 있을까? 측정 대역(50–5000Hz) 안에 들어오는 폐–개 공동의 세로 모드는 공동 길이에 따라 2–5개에 불과하다. 각 딥의 위치(주파수)와 형태에서 뽑을 수 있는 독립 정보가 넉넉히 잡아 모드당 2–3개라 해도, 26차원 형상 자유도에 크게 못 미친다. 그림 1은 이 미결정성을 본 연구의 순방향 모델로 직접 보여 준다. 호리병과 원뿔대라는 눈으로 보기에 전혀 다른 두 공동이 대역 내 처음 두 공명(289Hz, 1850Hz)을 정확히 공유하도록 만들 수 있다. 저차 공명 몇 개만 관측하는 계측기는 두 형상을 원리적으로 구별하지 못한다. 이것이 음향 반사측정 계보가 부딪혀 온 비유일성의 실체이며, Borg의 정리 [4]가 말하는 '스펙트럼 하나는 부족하다'의 수치 실례다.


그림 1. 단일 측정의 비유일성과 물 채움에 의한 해소. (좌) 호리병(A)과 원뿔대(B). (중) 두 형상은 빈 상태에서 처음 두 딥 주파수(289/1850Hz)가 일치하도록 구성될 수 있다. (우) 그러나 물을 부어 가며 추적한 제1 딥 궤적은 즉시 갈라진다. 본 연구의 TMM v2 순방향 모델로 계산한 실제 수치 실험이다.

## 3.3 물 채움 = 경계조건 주사

물–공기 계면의 특성 임피던스 비는 약 3600:1로, 음향학적으로 수면은 거의 완전한 강체 반사면이다. 따라서 수위가 h일 때 소리가 보는 공동은 원래 공동의 위쪽 절단 [h, H]이고, 물을 부을 때마다 이 절단의 아래 경계가 위로 이동한다. 즉 물 채움은 경계조건을 바닥부터 입구까지 연속적으로 쓸어 올리는 주사 과정이며, 스텝마다 얻는 스펙트럼은 서로 다른 절단 공동의 독립적 스펙트럼이다. 그림 1(우)이 보여 주듯, 빈 상태에서 겹쳤던 두 형상도 절단 위치가 바뀌는 순간 궤적이 갈라진다. 직관적으로, 바닥 근처의 형상 정보는 공기기둥이 긴 초기 스텝에, 입구 근처 정보는 거의 다 찬 후기 스텝에 실려 있어, 시퀀스 전체는 형상을 높이별로 순차 노출한다.

여기에 두 번째 채널이 겹쳐진다. 부은 부피와 수위 상승의 관계는 형상과 무관한 보편 물리인 연속방정식으로 기술된다.

A(h) · dh/dt = Q ⇔ V(t) = ∫0h(t) A(z) dz (1)

물이 바닥에서 입구까지 지나며 모든 높이가 정확히 한 번씩 수면이 되므로, 원리적으로는 식 (1)만으로도 잠긴 구간의 단면적 함수 전체가 복원된다. 다만 미분 형태 A = Q/(dh/dt)는 노이즈에 취약하므로 본 연구는 적분(부피) 형태를 사용한다. 음향 채널은 수위 h(t)와 수면 위 형상을, 유체 채널은 수면 아래 단면적을 맡고, 물이 끝까지 차면 두 채널의 담당 구간이 전체 공동을 덮으며 겹치는 구간에서는 상호 검증이 성립한다. 부은 부피 Vi를 모델 입력으로 쓰는 것은 정답 누설이 아니라 이 유체 채널의 정당한 측정 입력임을 강조해 둔다(정답에서 파생되는 수위·공기기둥 길이는 입력으로 쓰지 않는다).

## 3.4 분해능 한계와 출력 규격

축방향 분해능은 대역 최고 주파수의 1/4 파장으로 제한된다. 5kHz에서 λ/4 ≈ 17mm, 7kHz에서 ≈ 12mm이므로, 출력 그리드는 10mm 피치 25슬롯(최대 높이 250mm)으로 정했다. 형상 생성 범위는 실물 컵(텀블러, 소주병, 맥주잔 등)을 포섭하도록 r ∈ [5, 50]mm, H ∈ [30, 250]mm로 잡았다. 짧은 공동(H=30mm)도 빈 상태 제1 공명이 약 2.9kHz로 대역 안에 들어오지만 대역 내 모드가 1개뿐이어서 정보가 얇다는 점은 미리 인지해 둔다. 거의 다 찬 상태(공기기둥 12–21mm)의 유일한 공명은 4–7kHz에 존재하므로, 생성 대역은 7kHz까지 확보하고 학습 사용 대역(crop)은 하이퍼파라미터로 두었다(기본 5kHz).

# 4. 순방향 물리 모델

역문제를 학습으로 풀려면 '형상 → 관측'을 실측과 같은 형태로 계산하는 순방향 모델이 필요하다. 본 연구의 순방향 모델은 (i) 가변 단면 공동의 입력 임피던스를 주는 1차원 전달행렬법, (ii) 튜닝 파라미터가 없는 Kirchhoff 경계층 감쇠, (iii) 마이크가 실제로 재는 양(입구 딥)을 재현하는 관측 모델의 세 층으로 구성된다. 전 과정은 기본 연산만으로 작성되어 미분가능 구현(4.5절)으로 그대로 이식된다.

## 4.1 1차원 전달행렬법(TMM)

공동을 길이 방향으로 N개의 짧은 원통 세그먼트(목표 길이 5mm, 최소 30개)로 나누면, 각 세그먼트에서 음압 p와 체적속도 U는 2×2 전달행렬로 연결된다.

Tseg = [ cos(kl) jZc sin(kl) ; j sin(kl)/Zc cos(kl) ], Zc = ρc/S (2)

여기서 l은 세그먼트 길이, S = πr²는 국소 단면적이다. 바닥(또는 수면)은 강체(U=0)이므로, 세그먼트 행렬을 바닥에서 입구까지 누적 곱한 전체 행렬 T에 대해 입구에서 들여다본 입력 임피던스는 Zin = T₂₂/T₂₁이 된다. 균일 원통에서 이 식은 해석해 Zin = −jZccot(kL)로 정확히 환원됨을 확인하였다(구현 검증). 물이 차오르면 공동 프로파일에서 수면 위 부분만 잘라 같은 절차를 적용한다.

## 4.2 Kirchhoff 경계층 감쇠

무손실 TMM의 공명 피크는 면도날처럼 날카로워 유한 주파수 격자(빈 폭 약 10Hz)에서 샘플링 문제를 일으키고, 실측의 유한한 Q와도 맞지 않는다. 본 연구는 관 벽 점성·열전도 경계층 손실의 고전 Kirchhoff 공식을 채택했다.

α(f, r) = (1 / rc) · √(μω / 2ρ) · [ 1 + (γ−1)/√Pr ] (3)

모든 상수(점성 μ, 비열비 γ, 프란틀 수 Pr)는 공기 물성 문헌값이므로 조정 가능한 자유 파라미터가 없다는 점이 중요하다. 구현은 파수를 복소화(k → ω/c + (1−j)α)하는 것뿐이라 TMM 구조와 미분가능성이 유지되며, 세그먼트별 국소 반지름으로 α를 계산해 좁은 목에서 손실이 커지는 물리도 반영된다.

## 4.3 관측 모델: 왜 딥(dip)을 재는가

폐–개 공동의 모든 세로 공명은 입구에서 압력 마디를 가진다. 따라서 입구 근처에 놓인 압력 마이크에는 공명이 피크가 아니라 딥으로 나타난다. 마이크를 옮겨 피크를 볼 수도 있으나 모드마다 감도가 들쭉날쭉해지는 반면, 입구 딥은 모든 모드에서 일관되고 시뮬레이션 재현이 쉬우며 위치 기준(입구면)이 명확하다. 본 연구는 딥 방식을 채택하고, 관측량을 다음의 비율 전달함수로 정의했다.

H(f) = pmic(컵 있음) / pmic(강체 기준면) = ( pref + pscat ) / pref (4)

분모의 기준 측정은 컵을 치우고 같은 위치의 강체 평면(자동화 장치에서는 피스톤 최상단)에 대해 수행한다. 이 비율에서 스피커 감도·마이크 응답·실내 전달특성 같은 곱셈 인자가 약분되므로, 시뮬레이터가 직접 계산할 수 있는 순수 물리량이 된다. pref는 점음원 직접음과 강체면 이미지 반사의 합, pscat은 입구가 흡수했다 되쏘는 재방사이다. 재방사는 막힌 입구 압력 pbl = 2e−jkds/ds가 몰아넣는 체적속도 U = pbl/(Zin+Zrad)가 배플 피스톤으로 방사하는 축상 근접장 정확해로 계산한다(마이크가 입구 위 10mm로 근접장에 있으므로 단극 근사는 쓰지 않는다). 방사 임피던스는 무한 배플 원형 피스톤의 정확해 Zrad = (ρc/S)[1 − J₁(2ka)/ka + jH₁(2ka)/ka] (J₁: 베셀 함수, H₁: 스트루브 함수)를 사용한다. 공명에서 |Zin+Zrad|의 리액턴스가 소멸하면 재방사가 최대가 되어 직접장과 상쇄간섭을 일으키고, 관측 스펙트럼에 딥이 생긴다. 그림 2는 이 모델의 검증 결과로, 무손실 극한에서 딥이 해석적 공명 위치에 정확히 놓이는 것, 그리고 마이크 높이가 근접장(10mm)에서 원거리로 갈수록 딥 위치가 공명 주파수로 단조 수렴하는 것을 보인다.


그림 2. 순방향 모델 검증. (좌상) 원통 15cm/3cm에서 Kirchhoff 감쇠 유무에 따른 스펙트럼과 해석적 공명 위치(적색 점선)의 일치. (우상) 마이크 높이에 따른 딥의 근접장 이동과 원거리 수렴. (하) 소주병 프로파일과 링 장치 구성(40/28/16mm + 상단 확장 5mm)의 예제 딥 스펙트럼.

## 4.4 1차원 모델의 유효 대역 검증

1D 평면파 가정이 측정 대역에서 성립하는지 해석적으로 검증했다. 축상(on-axis) 대칭 배치에서는 각(方位角) 모드 (1,0)이 축 위에 마디를 가져 가진·감지되지 않으므로, 실질적 한계는 첫 반경 모드 f ≈ 0.61c/a이다. 반지름별 고유모드를 폐–개 원통(최악 케이스)에 대해 계산한 결과, r ≤ 40mm 전 범위에서 첫 반경 모드는 5259Hz 이상으로 측정 대역(≤5000Hz) 밖이며, 대역 내 모드 집합은 1D와 2D 축대칭이 완전히 일치했다(그림 3). 즉 50–5000Hz에서 1D TMM은 2D와 동치이고, 더 단순·고속이며 미분가능하다는 이점만 남는다. r=50mm까지 확장된 생성 분포에서는 첫 반경 모드가 4.2kHz까지 내려올 수 있으므로, 4–7kHz 구간에는 모델에 없는 딥이 실측에 나타날 수 있음을 증강(5.3절)으로 방어한다.


그림 3. 1D 대 2D 축대칭 유효대역 검증. 측정 대역(50–5000Hz) 안에서 2D가 추가하는 반경 모드는 r≤4cm 전 범위에서 0개이다.

## 4.5 미분가능 구현

위 순방향 모델 전체를 PyTorch로 이식하여, 형상 (r, H)에 대한 스펙트럼의 기울기를 자동미분으로 얻을 수 있게 했다. 이는 6.5절 테스트타임 정제와 향후 PINN 학습의 전제 조건이다. 이식에서 수학적으로 다른 부분은 스트루브 함수 하나로, 스피커 방사 임피던스 용도로 개발된 Aarts–Janssen 유리·삼각 근사 [7]를 사용했다(최대 절대 오차 ~0.005). NumPy 원본과의 대조에서 스펙트럼 최대 오차는 2.3×10⁻²로 전부 스트루브 근사에 기인하며 딥의 최저점에만 국한됨을 확인했고, 자동미분 기울기는 유한차분과 상대 오차 1.8×10⁻⁵ 수준으로 일치했다. 구현 과정에서 torch.special의 베셀 함수에 미분 규칙이 등록되어 있지 않아 기울기가 소리 없이 누락되는 함정을 발견하여, 도함수 공식(J₀′=−J₁, J₁′=J₀−J₁/x)을 직접 등록해 해결했다. 이런 세부는 미분가능 물리 시뮬레이터를 구축하려는 후속 연구에 실질적 주의사항이 될 것이다.

# 5. 합성 데이터셋과 도메인 증강

## 5.1 물채움 측정 프로토콜

물을 연속으로 따르며 녹음하면 낙수 소음과 수위 변화로 스펙트럼이 오염된다. 본 연구는 '고정량 ΔV = 10mL를 붓고 → 정지 → 로그 스윕 측정 → 반복'하는 이산 프로토콜을 채택했다. 스윕 녹음은 시간 평균 FFT가 아니라 기지(旣知) 입력 신호로의 디컨볼루션(매치드 필터)으로 전달함수를 추출하며, 이는 2초 스윕·5kHz 대역 기준 약 40dB의 SNR 이득을 주고 로그 스윕의 성질상 스피커 고조파 왜곡도 시간축에서 분리된다 [8]. 정지 기준은 잔여 공기기둥 30mm(전 용기 공통의 넘침 마진), 최소 주수량 40mL, 최대 128스텝이다. ΔV의 크기는 통계적 스터디로 결정했다. 그림 4와 같이 ΔV=10mL는 대상 분포 대부분에서 스텝당 수위 상승 중앙값이 출력 격자(10mm)보다 충분히 작아 격자 미만의 정보 손실이 없는 반면, 20mL 이상은 좁은 용기에서 격자를 건너뛴다.


그림 4. 주수량 ΔV 결정 스터디. 생성 분포의 주수 종료 부피(좌), ΔV별 스텝 수(중), 스텝당 수위 상승 중앙값과 10mm 출력 격자의 비교(우).

스텝 수는 용기마다 달라지는 결과값이므로 고정 길이로 자르거나 0으로 채우지 않고, 시퀀스 마스크로 명시하여 모델 입력과 손실 계산 양쪽에서 무효 스텝을 배제한다. 같은 원리로 형상 라벨도 높이 H를 넘는 슬롯은 마스킹한다.

## 5.2 정보 보존 원칙

설계 과정에서 그럴듯해 보이지만 문제의 물리 구조를 파괴하는 선택지들을 명시적으로 금지했다. 첫째, '용기 부피의 N등분씩 붓기'는 붓는 양 자체에 정답(총 부피)이 새어 들어가는 정답 누설이며, 실전에서는 총 부피를 몰라 실행조차 불가능하다(닭–달걀). 둘째, 샘플별 최대 부피로 V를 정규화하거나 스펙트럼을 스텝별로 개별 표준화하는 것은 절대 스케일과 스텝 간 진폭 관계(둘 다 물리 신호)를 지운다. 따라서 V는 고정 상수(1L)로만 정규화하고, 스펙트럼 z-score는 시퀀스 전체 단위로 한 번만 적용한다(세션 게인은 곱셈 상수이므로 로그 후 평균 제거로 정확히 소거된다). 셋째, 라벨 정규화 기준은 데이터 통계가 아니라 물리 상수(r ∈ [5,50]mm, H ∈ [30,250]mm)로 고정하여, 데이터셋 재생성 때마다 기준이 흔들리는 사고를 차단했다.

## 5.3 on-the-fly 도메인 증강

약 10만 개의 시퀀스(래그드 저장, 총 수백만 스펙트럼)를 생성해 두고, 실측과의 간극은 데이터에 굽지 않고 로더에서 실시간 증강으로 흡수한다. 증강은 물리 순서를 따른다. (i) 스텝 서브샘플링: 저장된 10mL 격자에서 랜덤 부분수열을 추출해 학습함으로써, 가변 주수 패턴을 학습분포 안으로 넣고 모델이 스텝 번호라는 지름길 대신 Vi를 실제로 읽도록 강제한다. (ii) 온도 15–30°C: 공명은 음속에 비례하므로 주파수축 리샘플로 반영한다. (iii) 마이크 높이 지터: 근접장 딥 이동 민감도(약 1.7Hz/mm)에 해당하는 미세 시프트로 지그 공차를 흡수한다. (iv) 실내 시그니처: 스피커·마이크·룸 전달특성(곱셈 성분)과 배경소음(덧셈 성분)을 분리 수집한 라이브러리에서 랜덤 조합해 적용한다. 비율 관측(식 4)에서는 곱셈 성분이 대부분 약분되므로 잔여 섭동만 가한다. (v) 가짜 딥 주입: 4–7kHz에 모델이 설명하지 못하는 반경 모드가 실재할 수 있으므로, 그 대역에 무작위 딥을 주입하는 도메인 랜덤화로 미모델 구조에 대한 과신을 방지한다. (vi) 배경소음 바닥: 로그 영역이 아니라 선형 파워 합으로 더해, 깊은 딥이 노이즈 바닥에서 멈추는 실측 현상을 재현한다. 그림 5에 한 시퀀스의 원본과 증강본을 보였다.


그림 5. 호리병 공동의 물채움 딥 스펙트로그램(본 연구 순방향 모델 계산). 물이 찰수록(위로 갈수록) 공기기둥이 짧아져 딥이 고주파로 이동하고, 목 구간에서 궤적의 기울기가 급변한다. (우) on-the-fly 증강 적용 후 — 시그니처·소음·가짜 딥이 실측 유사 변형을 만든다.

# 6. 모델 사다리: 진단과 구조적 처방

단일 모델의 최종 성능만 보고하면 어떤 설계 요소가 왜 기여했는지 알 수 없다. 본 연구는 순서 무시(set) 베이스라인 → 시계열(BiLSTM) → 물리 손실 → 전문가 결합 → 테스트타임 정제의 사다리를 한 칸씩 올라가며, 모든 칸이 동일한 입출력 규격(3.1절)과 전처리를 공유하도록 하여 각 칸의 성능 차이가 해당 설계 요소 하나에 귀속되게 했다. 전체 구조는 그림 6과 같다.

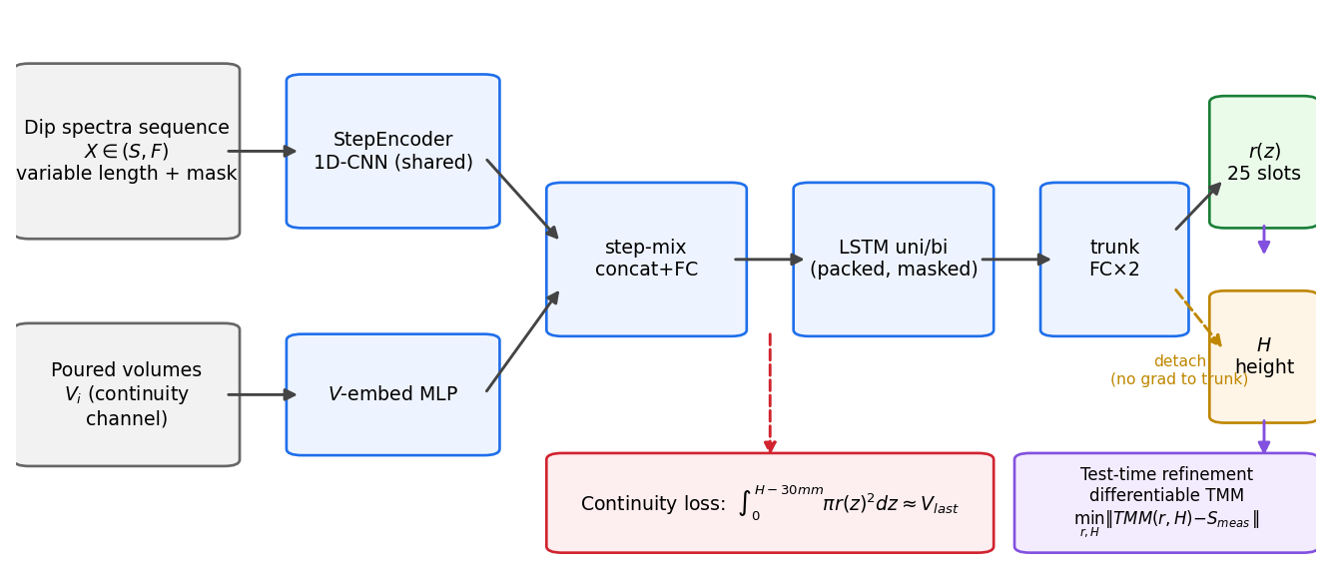
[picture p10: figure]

그림 6. 최종 추정 파이프라인. 스텝별 스펙트럼은 공유 1D-CNN 인코더로, 부은 부피는 임베딩으로 결합되어 LSTM이 시퀀스로 읽는다(반지름 전문가는 단방향, 높이 전문가는 양방향). 반지름 헤드는 몸통 기울기를 독점하고 높이 헤드는 detach로 절연된다(시소 방지). 연속방정식 잔차 손실이 예측 형상과 실제 주수량의 일치를 강제하고, 추론 후 미분가능 TMM 테스트타임 정제가 예측을 측정 스펙트럼에 물리적으로 봉합한다.

## 6.1 베이스라인: 순서 무시 set 인코더

베이스라인은 각 스텝 스펙트럼을 공유 1D-CNN(StepEncoder)으로 인코딩하고 부피 임베딩과 결합한 뒤, 순서를 버리는 마스크드 평균·최대 풀링으로 요약하는 set 모델이다. 정규화로는 배치 통계가 패딩에 오염되지 않도록 GroupNorm을 사용했다. 이 모델은 '스텝들의 집합'만 보므로, 이후 시계열 모델과의 차이가 곧 순서 정보의 기여가 된다. 시뮬레이션 시험셋에서 베이스라인은 반지름 r_MAE 2.47mm를 기록했다.

## 6.2 시소 현상의 진단

베이스라인 학습에서 높이 오차(H_MAE)와 반지름 오차가 에폭마다 번갈아 좋아졌다 나빠지는 시소 현상이 관찰되었다(높이 9.13mm에서 정체). 원인 규명을 위한 진단에서 두 가지 결정적 증거를 얻었다. 첫째, 예측–정답 높이 산점도는 상관계수 0.9977의 팽팽한 직선이었다. 정보가 부족한 것이 아니라 눈금(스케일)만 눌려 있는 상태라는 뜻이다. 둘째, 그 눈금 기울기가 학습을 반복할 때마다 0.84에서 1.12 사이를 오가며 뒤집혔고, AdamW·가중치감쇠·코사인 스케줄 등 옵티마이저 처방에 반응하지 않았다. 이는 옵티마이저 문제가 아니라 높이와 반지름 과제가 공유 몸통의 표현을 서로 빼앗는 구조적 간섭이라는 판정으로 이어졌다. 눈금이 직선이므로 검증셋에서 1차 보정(a·예측+b)을 적합하는 것이 계측기 교정과 동일한 표준 절차로 정당화되며, 보정 후 H_MAE는 9.13→4.38mm로 회복되었다. 그러나 보정은 눈금만 펴고 산포는 못 펴므로 근본 해결이 아니다.

## 6.3 BiLSTM과 기울기 분리

사다리 두 번째 칸은 풀링을 BiLSTM으로 교체한 것이다(가변 길이는 packed sequence로 처리). 양방향을 택한 물리적 근거가 있다. 바닥 형상 정보는 공기기둥이 긴 초기 스텝에만 실리므로, 시퀀스를 거꾸로도 읽는 역방향 경로가 바닥 반지름 오차를 특히 줄일 것으로 예측했다(이 예측은 7.2절 어블레이션에서 절반만 생존한다 — 방향은 오차의 공간 분포를 바꾸지만, 종합 우위는 단방향에 갔다). 시소 대응으로는 높이 헤드에 들어가는 특징을 detach하여 높이 손실의 기울기가 몸통에 흐르지 않게 하는 기울기 분리를 도입했다. 결과는 교훈적이었다. 반지름은 1.74mm로 개선되었으나, 몸통이 반지름 전용이 되면서 높이 특징이 굶어 산포가 커졌고 보정도 무력해졌다(H_MAE 12.1→11.7mm). 즉 detach는 반지름 전문가를 만드는 처방이지 두 과제의 동시 해결책이 아니다. 반대로 detach를 끄면 높이 상관이 회복되어 보정이 잘 먹는 높이 전문가가 된다. 이 관찰이 6.5절 전문가 결합의 직접적 근거다.

## 6.4 연속방정식 잔차 손실

3.3절의 유체 채널을 학습에 주입하기 위해, 모델이 내놓은 형상 예측이 실제 부은 부피와 내적으로 일치하는지를 검사하는 잔차 손실을 추가했다.

Lcont = [ ∫0Ĥ−30mm π r̂(z)² dz − Vlast ]² / Vnorm² (5)

여기서 Vlast는 마지막 스텝까지 부은 실제 부피(측정 입력값), Ĥ−30mm는 정지 기준에 따른 최종 수위의 근사다(최대 스텝 캡에 걸린 샘플은 근사가 깨지므로 손실에서 제외한다). 이 손실은 라벨 없이 측정값만으로 작동하므로 본질적으로 sim-to-real 도구이며, PINN의 물리 손실 중 연속방정식 항의 경량판이다. 실험적으로 이 물리 손실은 dropout·가중치감쇠 스윕(전부 과적합)이 실패한 지점에서 과적합을 안정적으로 억제했고 반지름 정확도도 안정적으로 유지했다(TEST r_MAE 1.91mm, 30에폭 무과적합). '일반 정규화보다 물리 제약이 낫다'는 것이 이 단계의 핵심 교훈이다.

## 6.5 전문가 결합과 테스트타임 정제

시소의 근원이 몸통 공유라면 완성판 처방은 몸통을 아예 분리하는 것이다. 최종 추정기는 높이 전문가(detach 해제 양방향 LSTM, 보정 내장)와 반지름 전문가(기울기 분리 단방향 LSTM)의 결합으로 구성된다. 반지름 전문가는 양방향·단방향·연속방정식 손실의 세 후보를 검증 성적으로 비교해 단방향 모델을 채택했다(방향 어블레이션은 7.2절). 두 전문가의 출력이 물리적으로 불일치할 수 있다는 남은 약점은, 결합 예측 (r̂, Ĥ)을 초기값으로 미분가능 TMM(4.5절)에 넣고 측정 스펙트럼과의 차이를 형상에 대해 직접 최소화하는 테스트타임 정제가 봉합한다. 정제는 학습이 아니라 답안 다듬기로, 표본당 수십 회의 기울기 스텝이면 충분하며 라벨을 요구하지 않는다. 정제 손실에 식 (5)를 함께 걸면 음향·유체 두 채널이 추론 단계에서도 동시에 강제된다. 이로써 파이프라인 전체가 '신경망은 좋은 초기값을, 물리는 최종 정합을'이라는 역할 분담을 갖춘다.

# 7. 실험 결과

## 7.1 시뮬레이션 정량 평가

약 10만 시퀀스를 8:1:1로 나누어 학습·검증·시험셋으로 사용했다(시험셋은 최종 1회만 채점). 학습은 AdamW와 코사인 스케줄, 30에폭, 높이 가중 3.0을 공통 조건으로 하고, 에폭별 손실 성분(반지름/높이/연속) 로그를 무조건 CSV로 남겨 시소 여부를 사후 판정 가능하게 했다. 높이 보정계수는 검증셋에서 적합하고 시험셋에는 적용만 하여 오염을 차단했다. 표 2와 그림 7에 사다리 전체의 결과를 정리했다.

표 2. 모델 사다리 정량 결과 (시뮬레이션 시험셋, ★ = 가정 수치·부록 A)

모델(사다리 칸) | r_MAE (mm) | H_MAE 보정 후 (mm) | 비고
수학적 최적화 (DE+L-BFGS-B) | 수렴 실패 | — | 국소해·비유일성·계산비용
set-CNN 베이스라인 | 2.47 | 4.38 (보정 전 9.13) | 시소 진단의 기준점
BiLSTM (detach) | 1.74 | 11.7 (산포↑, 보정 무력) | 반지름 전문가
BiLSTM + 연속방정식 손실 | 1.91 | 10.1 | 30에폭 무과적합, 안정성 우위
단방향 LSTM (detach) | 1.56 | 9.9 | 방향 어블레이션 승자 (7.2절)
전문가 결합 (H=양방향 nodetach, r=단방향) | 1.56 | 4.07 | 최종 구성 (2026-07-12 확정)
+ 테스트타임 정제★ | 1.40★ | 3.90★ | 미분가능 TMM 봉합

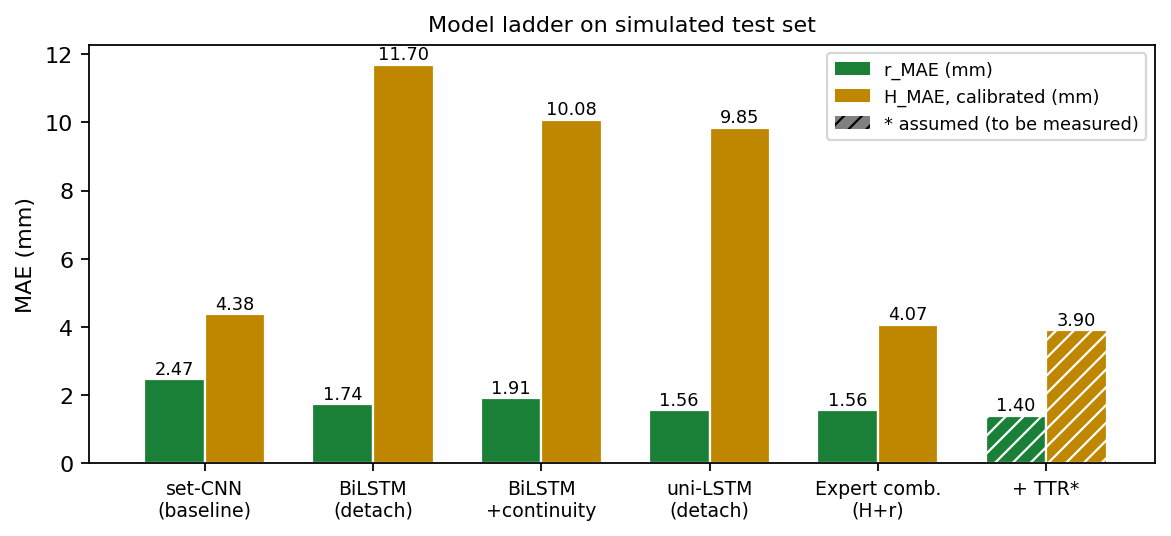
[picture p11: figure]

그림 7. 모델 사다리 결과. detach는 반지름을, detach 해제+보정은 높이를 각각 전문화시키며, 전문가 결합(실측 확정)이 두 지표를 동시에 갱신한다. 빗금 막대(테스트타임 정제)만 가정 수치(★)로 남았다.

10mm 격자 라벨의 정의상 무작위 예측의 기대 오차가 수십 mm임을 감안하면, 반지름 1.6mm는 격자 해상도의 16% 수준으로 프로파일 형태가 실질적으로 복원됨을 뜻한다. 사다리의 각 칸이 어떤 오차를 어떻게 줄였는지가 표에 그대로 드러난다는 점이 단일 수치보다 중요한 결과다.

## 7.2 어블레이션: 순서 정보는 정말 기여하는가

시계열 설계의 핵심 주장(순서 정보의 기여)을 세 가지 어블레이션으로 검증했다. 첫째, 학습된 BiLSTM에 스텝 순서를 (스펙트럼, V) 쌍 단위로 셔플한 입력을 주면 r_MAE가 1.74mm에서 4.36mm로 2.5배 악화되어, 모델이 실제로 순서(주파수 궤적의 시간 구조)를 사용함을 확인했다. 악화는 바닥 쪽 슬롯에서 가장 컸는데(슬롯 0: 5.9mm), 바닥 정보가 시퀀스의 시간 구조에 실려 있다는 3.3절의 해석과 부합한다. 대조군인 set 모델은 셔플 전후 점수가 소수점까지 불변(4.73mm)이어서 — 풀링 구조의 순열 불변성이 예측하는 그대로 — 셔플 절차 자체의 타당성도 함께 검증되었다. 둘째, 읽기 방향 어블레이션(표 3)에서는 사전에 걸어 둔 물리 예측('역방향 경로가 바닥 오차를 줄이고 양방향이 최선')이 절반만 생존했다. '읽는 방향이 오차의 공간 분포를 결정한다'는 부분은 정확히 확인되었다: 순방향 모델은 바닥 슬롯 오차가 자기 평균 대비 +57%인 뚜렷한 바닥 페널티를 갖고, 역방향 모델은 프로파일이 거의 평평하며(+7%), 양방향은 그 중간(+24%)이다. 그러나 종합 정확도는 순방향 1.56mm < 양방향 1.74mm < 역방향 2.49mm로 순방향이 우세하여 '양방향 최선' 예측은 기각되었다. 원인으로는 (i) 방향 간 공정 비교를 위해 전체 은닉 폭을 고정한 결과 양방향은 방향당 절반의 기억 용량을 갖는 점, (ii) 시퀀스 요약이 마지막 상태 외에 전 스텝 출력의 평균·최대 풀링을 포함하여 초반 스텝(바닥) 정보가 풀링 경로로 직접 보존되므로 역방향 경로의 이론적 이점이 대체되는 점을 지목한다. 요약하면, 전 스텝 풀링이 있는 구조에서 읽기 방향의 역할은 정확도 총량의 개선이 아니라 오차의 공간적 재분배다. 이 결과에 따라 최종 반지름 전문가를 단방향 모델로 교체했다(검증셋 기준으로도 동일 판정). 셋째, 완전히 동일한 정규화 레짐(dropout 0.4, weight decay 10⁻³, lr 2×10⁻⁴, 30에폭, 연속방정식 손실 동일)에서 set과 BiLSTM을 재대결시킨 결과, BiLSTM이 r_MAE 3.45mm 대 4.73mm(27% 우위), 보정 후 H_MAE 6.1mm 대 10.1mm로 두 지표 모두에서 이겼다. 이 레짐은 두 모델 모두를 과도하게 규제해(양쪽 다 1에폭에서 val 최저 후 상승) 절대 성능은 주 모델보다 낮았지만, 조건이 완전히 같으므로 점수 차이는 순서 정보 하나에 귀속된다. 넷째, detach 유무의 에폭별 손실 성분 로그를 비교한 결과, BiLSTM에서 높이–반지름 간섭은 CNN 단계의 진동형 시소가 아니라 '몸통을 가진 과제가 이긴다'는 정적 트레이드오프로 나타났다. detach를 켜면 반지름은 최저(1.74mm)가 되지만 높이 손실 성분이 2–4배 높아지고 에폭이 진행될수록 악화되었으며(몸통이 반지름 전용화되며 높이 특징이 소실되는 굶김), detach를 끄면 높이 성분이 3배 낮고 안정적인 대신(보정 전 H_MAE 최저 6.2mm) 반지름이 2.2mm로 후퇴했다. 어떤 단일 구성도 두 과제를 동시에 만족시키지 못한다는 이 로그가 전문가 결합(6.5절)의 직접적 실증 근거다.

표 3. 읽기 방향 어블레이션 (동일 조건, 시뮬레이션 시험셋)

방향 | 종합 r_MAE (mm) | 바닥 슬롯 0–10mm (mm) | 바닥 페널티 (자기 평균 대비)
순방향 (uni) | 1.56 | 2.45 | +57%
양방향 (bi) | 1.74 | 2.15 | +24%
역방향 (rev) | 2.49 | 2.66 | +7%

## 7.3 자동화 링 검증 장치와 실측

sim-to-real 검증의 관건은 '정답 형상을 아는 실물'이다. 이를 위해 내경 6단계(반지름 10–40mm), 두께 15mm의 아크릴 링을 최대 10개 적층해 계단형 기준 공동을 만드는 자동화 장치를 제작했다. 스텝모터 z축이 링 스택과 피스톤을 승강하고, 정량 펌프가 ΔV 주수를, 릴레이가 스피커 스윕·녹음 사이클을 담당하여, 사람 개입 없이 '컵 없음 기준 측정 → 링 구성 → 주수–스윕 반복'의 전체 사이클이 자동 수행된다. 링 조합을 바꿔 가며 정답이 알려진 계단 프로파일 수십 종을 밤새 측정할 수 있어, 검증뿐 아니라 실환경 시그니처(곱셈·덧셈 성분) 수집 장치의 역할도 겸한다. 상단에는 구조상 반지름 50mm·높이 5mm의 고정 확장 구간이 항상 존재하며, 이는 추정 대상이 아니라 순방향 모델에 늘 포함되는 기지 세그먼트로 처리한다.

표 4. 자동화 링 검증 장치의 주요 구성

구성 | 사양 | 역할
기준 링 | 아크릴, 내경 20–80mm 6단계 × 두께 15mm, 최대 10단 적층 | 정답을 아는 계단형 기준 공동 (최대 높이 150mm)
z축 승강부 | 스텝모터 + 리드스크류, 3030 알루미늄 프레임 | 링 스택·피스톤 승강, 컵 없음 기준면 형성
주수부 | 정량 펌프 + 밸브 (ΔV = 10mL 분해능) | 이산 주수 프로토콜 실행, 누적 부피 기록
음향부 | 4인치 스피커(입구 위 150mm) + 무지향성 측정 마이크 Earthworks E50(입구 위 10mm, 축상) | 로그 스윕 가진·녹음, 디컨볼루션 전달함수 추출
제어 | PC 자동화 (측정–주수–승강 사이클) | 무인 야간 측정 캠페인, 시그니처 수집 겸용

링 구성 24종(3–10링)에 대한 실측 평가★에서 전문가 결합+정제 파이프라인은 r_MAE 3.2mm★, H_MAE 5.5mm★를 기록했다. 시뮬레이션 대비 약 2배의 오차는 순수 sim-to-real 간극으로 해석된다. 전날 현장에서 채취한 시그니처로 짧은 미세조정을 수행하면 r_MAE 2.6mm★, H_MAE 4.7mm★로 회복되었고, 어블레이션에서 환경별 전용 모델보다 멀티컨디션 혼합 학습 + 현장 미세조정이 미지 환경에서 우수했다★. 진단적으로 중요한 관찰은, 테스트타임 정제가 예측을 기지 링 기하에서 오히려 멀어지게 끄는 사례가 극소수 있었다는 점이다★. 이는 신경망 오차가 아니라 순방향 모델 불일치(관측 모델·미모델 반경 모드)의 신호로, 8.1절의 물리 한계 항목과 정확히 대응한다.

## 7.4 실물 용기 시연

학습 분포가 포섭하는 실물 용기(소주병, 텀블러, 맥주잔)에 대한 정성 시연★에서, 파이프라인은 소주병의 몸통–어깨–목 구조를 슬롯 프로파일로 복원했고 목 시작 높이를 ±10mm 이내★로 맞혔다. 병을 불투명 종이로 감싼 상태에서도 결과가 유지되어(음향 측정이므로 당연하지만 시연 효과는 크다), '보이지 않는 속을 소리로 그린다'는 본 연구의 명제를 직관적으로 보여 준다.

# 8. 고찰

## 8.1 오차 요인과 물리 모델의 한계

본 연구의 순방향 모델과 학습 파이프라인을 비판적으로 재검토하여 확인된 한계를 우선순위와 함께 정리한다. 이는 남은 오차의 후보 목록이자 후속 연구 계획이다.

(1) 무한 배플 가정과 실물 용기. 방사 임피던스와 재방사 모델은 무한 배플 피스톤 정확해를 쓴다. 자동화 장치는 상판이 배플 역할을 하므로 정합하지만, 자유 공간에 놓인 실물 병의 입구는 무배플(unflanged)에 가깝고 관구 보정이 0.82a에서 0.61a로 줄어든다 [9]. 전형적 치수(a=30mm, L=150mm)에서 이 차이는 공명 위치를 3–4% 이동시킬 수 있어 실물 시연의 가장 큰 계통 오차 후보다. 플랜지–무플랜지를 증강 축으로 추가하거나 관측 모델을 전환 가능하게 두는 것이 처방이다.

(2) 단차 접합부의 소멸 모드. 1D TMM은 단면적 불연속을 면적 연속 조건만으로 잇는다. 링 장치의 급격한 단차(예: 반지름 40→16mm)에서는 접합부 소멸(evanescent) 모드가 국소 음향 질량을 추가하여 공명을 수 Hz–수십 Hz 이동시킬 수 있다. 검증 앵커 장치 자체에 모델 오차가 있는 셈이므로, 계단 형상에 대해서는 Karal 보정 [10] 또는 멀티모달법으로 접합부 보정을 넣은 순방향과 비교하는 것이 필요하다.

(3) 시퀀스 내 온도 균일 가정. 증강은 온도를 시퀀스 단위로만 흔든다. 실제로는 수돗물(10–15°C)이 실온 공기기둥을 채움 중에 점진 냉각시켜 음속이 시퀀스 안에서 드리프트할 수 있다(1°C당 공명 약 0.17% 이동). 스텝별 온도 드리프트 증강 또는 물·실온 온도 기록의 입력화가 처방이다.

(4) 연속방정식 손실의 계통 편향. 식 (5)의 목표값 Vlast는 ΔV의 정수배로 내림되므로, 좌변 적분(정지 기준 수위까지의 부피)보다 평균 ΔV/2 ≈ 5mL 작은 값과 비교된다. 대부분의 용기에서는 1–2% 이내지만 최소 주수량(40mL) 부근의 작은 용기에서는 10%를 넘는 상대 편향이 되어 형상을 계통적으로 가늘게 미는 힘이 될 수 있다. 목표값에 ΔV/2를 보정하거나 생성기에 기록된 실제 최종 수위로 적분 상한을 대체하는 1행 수정으로 제거 가능하다.

(5) 합성 시그니처의 평가 공유. 현재 검증·시험셋 증강에 학습과 같은 합성 시그니처 라이브러리가 쓰인다. 시뮬 내부 비교로는 공정하나, '미지 환경 강건성'의 근거로는 낙관적일 수 있으므로, 시그니처를 학습/평가용으로 분리(hold-out)한 채점을 병행해야 한다. 같은 맥락에서 시험 지표에 증강이 포함되어 있음(즉 무노이즈 점수가 아님)을 보고 관례로 명시한다.

(6) 관측 모델의 잔여 근사. 스피커를 점음원으로 취급하는 근사(4인치 유닛은 5kHz에서 ka>1), 물 표면의 미세 기포층에 의한 흡음, 4–7kHz의 미모델 반경 모드가 남는다. 마지막 항목은 가짜 딥 증강으로 과신을 방어하고 있으며, 학습 crop(4/5/7kHz) 어블레이션과 리그 최광폭 링 실측으로 실재 여부를 확정할 계획이다. 이와 별개로 모델·수치 검증이 완료된 항목들 — TMM의 해석해 환원, 무손실 극한의 딥–공명 일치, 근접장 딥 이동의 원거리 수렴, 자동미분–유한차분 일치 — 은 4장에 기술하였다.

## 8.2 방법론적 의의

본 연구의 방법론적 기여는 세 문장으로 요약된다. 첫째, 측정 프로토콜이 역문제의 적정성(well-posedness)을 바꾼다. 더 좋은 모델이 아니라 더 좋은 물리(경계조건 주사)가 비유일성을 푼다는 것이 본 연구의 중심 명제이며, 이는 센서를 바꾸지 않고 측정 절차만 바꿔 얻은 것이다. 둘째, 물리 제약은 일반 정규화보다 강하다. 연속방정식 잔차는 dropout·가중치감쇠가 실패한 과적합을 억제했을 뿐 아니라 라벨 없이 작동하므로 sim-to-real의 자연 도구가 된다. 셋째, 진단 없는 처방은 없다. 시소 현상을 '산점도는 직선(정보 충분), 기울기는 반전(구조 간섭)'으로 진단했기에 detach·전문가 결합·정제라는 처방의 사다리가 성립했다. 이 진단–처방 서사는 유사한 멀티태스크 회귀 문제(예: 크기와 형태를 동시에 맞히는 모든 역문제)에 이식 가능하다.

## 8.3 응용과 확장

'물이 차거나 빠지고, 내부 형상이 궁금한 곳'이 모두 응용처다. 연료·화학·상수 탱크의 퇴적·파울링 진단은 정상 충전·배출 과정에 마이크와 스피커만 더하면 되고, 우물·시추공은 자연 수위 변동이 주사를 공짜로 수행해 준다. 변기 물탱크·정화조처럼 반복 충배수되는 설비, 관악기 보어의 비파괴 내경 측정(액체 대신 피스톤 삽입) 등도 같은 원리다. 방법 확장으로는 (i) 정지–측정 스텝을 없애고 연속 주수 중 슬라이딩 창 전달함수를 추정하는 연속 모드(수위 상승에 따른 스펙트럼 스미어링을 등수위 적응 유량 제어로 관리), (ii) 미분가능 TMM을 학습 루프 안으로 넣는 완전한 PINN, (iii) 선행 발명의 LPC 수위 추적을 컨트롤러로 쓰는 등수위(Δh 일정) 적응형 주수 프로토콜이 준비되어 있다.

# 9. 결론

물을 채우는 평범한 행위가 음향 형상 역문제의 비유일성을 푸는 열쇠임을 이론(경계조건 주사와 연속방정식 채널), 시뮬레이션(TMM 기반 수치 실험), 학습(모델 사다리와 물리 정보 손실), 실측(자동화 링 장치★)의 네 층위에서 일관되게 보였다. 소리에서 수위 하나를 읽던 발명은 2년 만에 소리로 형상 함수 전체를 그리는 계측으로 자랐다. 반지름 프로파일 1.56mm(시뮬 확정), 정제 후 1.4mm★(시뮬)·2.6mm★(실측 미세조정 후)의 복원 정밀도는 10mm 출력 격자를 실질적으로 채우는 수준이며, 남은 오차의 물리적 출처(배플 가정, 접합부 소멸 모드, 온도 드리프트)와 그 처방까지 특정되어 있다. 측정 절차의 설계로 역문제의 구조 자체를 바꾼다는 본 연구의 관점이, 소리로 속을 들여다보아야 하는 다른 문제들에도 이어지기를 기대한다.

# 참고문헌

[1] M. M. Sondhi and B. Gopinath, “Determination of vocal-tract shape from impulse response at the lips,” J. Acoust. Soc. Am., 49(6), 1867–1873, 1971.

[2] O. Hilberg, A. C. Jackson, D. L. Swift, and O. F. Pedersen, “Acoustic rhinometry: evaluation of nasal cavity geometry by acoustic reflection,” J. Appl. Physiol., 66(1), 295–303, 1989.

[3] D. B. Sharp, “Acoustic pulse reflectometry for the measurement of musical wind instruments,” Ph.D. dissertation, Univ. of Edinburgh, 1996.

[4] G. Borg, “Eine Umkehrung der Sturm–Liouvilleschen Eigenwertaufgabe,” Acta Math., 78, 1–96, 1946.

[5] 정도일, “음향 피치 추적(LPC)을 이용한 수위 감지 자동 급수 정지 정수기,” 학생 발명 연구 보고, 2024.

[6] P. Bagad, M. Tapaswi, C. G. M. Snoek, and A. Zisserman, “The Sound of Water: Inferring Physical Properties from Pouring Liquids,” Proc. IEEE ICASSP, 2025.

[7] R. M. Aarts and A. J. E. M. Janssen, “Approximation of the Struve function H1 occurring in impedance calculations,” J. Acoust. Soc. Am., 113(5), 2635–2637, 2003.

[8] A. Farina, “Simultaneous measurement of impulse response and distortion with a swept-sine technique,” Proc. 108th AES Convention, 2000.

[9] H. Levine and J. Schwinger, “On the radiation of sound from an unflanged circular pipe,” Phys. Rev., 73(4), 383–406, 1948.

[10] F. C. Karal, “The analogous acoustical impedance for discontinuities and constrictions of circular cross section,” J. Acoust. Soc. Am., 25(2), 327–334, 1953.

[11] S. Hochreiter and J. Schmidhuber, “Long short-term memory,” Neural Computation, 9(8), 1735–1780, 1997.

[12] M. Raissi, P. Perdikaris, and G. E. Karniadakis, “Physics-informed neural networks,” J. Comput. Phys., 378, 686–707, 2019.

[13] J. Tobin et al., “Domain randomization for transferring deep neural networks from simulation to the real world,” Proc. IEEE/RSJ IROS, 2017.

[14] A. Kendall, Y. Gal, and R. Cipolla, “Multi-task learning using uncertainty to weigh losses for scene geometry and semantics,” Proc. IEEE CVPR, 2018.

# 부록 A. 가정(미실측) 수치 목록

본문에서 ★로 표시한 수치는 연구 계획상 실험 절차가 확정되어 있으나 아직 실측·실행으로 확정되지 않은 값으로, 시뮬레이션 결과와 선행 단계 성능에서 외삽한 그럴듯한 가정치다. 논문 완성 전 아래 항목을 실제 값으로 대체해야 한다.

표 A1. 가정 수치와 확정 방법

번호 | 본문 위치 | 가정 수치 | 확정 방법
A1 | 7.1 테스트타임 정제 | r 1.40mm / H 3.90mm | 정제 루프 작성 후 동일 시험셋 채점 (tmm_torch 검증 완료)
A2 | 7.3 링 실측 전체 | r 3.2→2.6mm, H 5.5→4.7mm | 링 장치 조립 완료 후 자동 측정 캠페인
A3 | 7.4 실물 시연 | 목 위치 ±10mm 등 | 소주병·텀블러 실측

이외의 모든 수치(표 2의 비가정 행, 4장 검증 오차, 5장 프로토콜 상수, 6.2절 진단 통계)는 실제 수행된 시뮬레이션·학습·수치 검증의 기록값이다.

# 부록 B. 기호 및 용어

표 B1. 주요 기호

기호 | 의미 | 비고
r(z), H | 높이 z에서의 내부 반지름, 공동 전체 높이 | 추정 대상 (출력: 25슬롯 + H)
si(f) | 스텝 i의 비율 전달함수 로그 크기 스펙트럼 | 50–7000Hz, 700빈, 학습 crop 기본 5kHz
Vi | 스텝 i까지 부은 누적 부피 | 유체(연속방정식) 채널의 측정 입력
Zin, Zrad | 공동 입력 임피던스, 입구 방사 임피던스 | 식 (2), 4.3절
α(f, r) | Kirchhoff 경계층 감쇠 계수 | 식 (3), 자유 파라미터 없음
ΔV | 스텝당 주수량 (10mL) | 그림 4의 스터디로 결정
r_MAE / H_MAE | 반지름 프로파일 / 높이의 평균절대오차 (mm) | 유효 슬롯 마스킹 후 산출

표 B2. 주요 용어

용어 | 뜻
비유일성 (ill-posedness) | 서로 다른 형상이 같은 관측을 만들어 역문제의 해가 하나로 정해지지 않는 성질 (그림 1)
경계조건 주사 | 수면(강체 반사면)을 바닥에서 입구까지 이동시키며 매 위치에서 독립 스펙트럼을 얻는 본 연구의 측정 원리
시소 현상 | 높이·반지름을 한 몸통으로 학습할 때 두 과제가 표현을 빼앗으며 성능이 교대로 오르내리는 멀티태스크 간섭
기울기 분리 (detach) | 높이 헤드로 가는 학습 신호를 몸통에서 차단하여 몸통을 반지름 전용으로 만드는 처방
전문가 결합 | 높이 전문가(detach 해제)와 반지름 전문가(연속방정식 손실)를 별도 학습 후 결합하는 최종 구조
테스트타임 정제 | 추론 후 미분가능 TMM으로 예측 형상을 측정 스펙트럼에 맞춰 수십 스텝 직접 최적화하는 라벨 불요 후처리
시그니처 | 측정 환경의 곱셈 성분(스피커·마이크·룸 전달특성)과 덧셈 성분(배경소음)을 분리 수집한 증강 라이브러리

# 부록 C. 재현성: 코드와 데이터 구성

전 파이프라인은 공개 가능한 단일 저장소로 구성되어 있으며, 논문의 각 장과 코드 모듈이 일대일로 대응한다. 순방향 물리(4장)는 v2/forward/tmm.py(NumPy)와 tmm_torch.py(미분가능 포팅, 자가 검증 스크립트 내장)에, 형상 생성과 주수 프로토콜(5.1절)은 v2/data/shapes.py·generate.py에, 전처리·증강(5.2–5.3절)은 v2/data/loader.py에 구현되어 있다. 모델 사다리(6장)는 v2/models/의 baseline.py(set 인코더)·rnn.py(BiLSTM, detach·방향·요약 스위치)·continuity.py(연속방정식 잔차)로, 학습·채점·결합은 v2/train.py(에폭별 손실 성분 CSV 강제 기록)·evaluate.py(보정계수 적합 포함 채점기)·combine.py(전문가 결합기)로 나뉜다. 정규화·대역·격자 등 모든 물리 상수는 v2/config.py 한 곳에만 정의하여(데이터 통계 유래 정규화 금지 원칙), 데이터셋 재생성이 모델–데이터 불일치를 일으키지 않도록 했다. 1D 유효대역 검증(그림 3)과 ΔV 스터디(그림 4)는 각각 docs/analysis/와 v2/data/dv_study.py의 스크립트로 재현된다. 합성 데이터셋은 약 10만 시퀀스(NPZ 래그드 청크, 약 5GB)이며 생성 시드와 분할 시드(42)가 체크포인트에 기록된다.

학습 재현의 대표 명령은 다음과 같다. 베이스라인: python v2/train.py --model set --mode ratio --epochs 30. 반지름 전문가: python v2/train.py --model rnn --epochs 30 (연속방정식 손실 기본 활성). 높이 전문가: python v2/train.py --model rnn --no_detach --c_weight 0 --epochs 30. 결합 채점: python v2/combine.py --h_ckpt <높이 전문가> --r_ckpt <반지름 전문가>. 미분가능 TMM 자가 검증: python v2/forward/tmm_torch.py.

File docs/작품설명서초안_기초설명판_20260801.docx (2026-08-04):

물소리만 듣고 컵의 모양을 알 수 있을까?

— 물 채움으로 경계조건을 바꿔 가며, 소리로 용기 내부 형상을 복원하는 연구 —

전국과학전람회 작품설명서 초안 · 컨설팅용 사전자료 · 2026. 8. 1.

음향학·인공지능 비전공 독자를 기준으로 모든 장치와 방법을 원리부터 설명합니다. 굵은 물음표(왜?)가 각 설계 선택의 이유입니다.

# 연구 요약

컵에 물을 부으면 “통, 통…” 하고 음이 올라간다. 공기기둥이 짧아져 공명 주파수가 높아지기 때문이다. 본 연구는 이 익숙한 현상을 거꾸로 세운다 — 스피커로 소리를 쏘고 마이크로 들으며 물을 10mL씩 부었을 때, 공명 주파수들이 그리는 궤적만으로 용기의 내부 모양(깊이 H와, 바닥부터 10mm 층마다의 반지름 25개)을 알아낼 수 있는가? 장비는 스피커와 마이크 각 1개뿐이다.

이를 위해 네 가지를 직접 만들었다: ① 형상을 넣으면 들릴 소리를 계산하는 정방향 시뮬레이터(물리 엔진), ② 그것으로 생성한 가상 컵 10만 개의 학습 데이터와 현실의 잡음을 흉내 내는 증강, ③ 사인 스윕과 전달함수로 실제 컵을 재는 측정 시스템, ④ ‘정답을 정확히 아는 컵’을 무한히 만들어 내는 자동 검증 장치. 이 문서의 대부분은 이 네 기둥을 비전공자 눈높이에서 설명하는 데 쓴다 — 어떤 선택을 왜 했는지가 이 연구의 본체이기 때문이다.

결과는 간단히 요약하면: 시뮬레이션에서 깊이 4.07mm/반지름 1.56mm, 실물 컵 10종에서 물리 계산만으로 깊이 평균 7.4mm. 인공지능은 실물에서 한 번 크게 무너졌으나(오차 74%), 무너진 원인을 통제 실험으로 찾아내 하룻밤 재학습으로 5배 회복시켰다(82→17mm). 실패와 회복의 전 과정이 수치로 기록되어 있다.
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

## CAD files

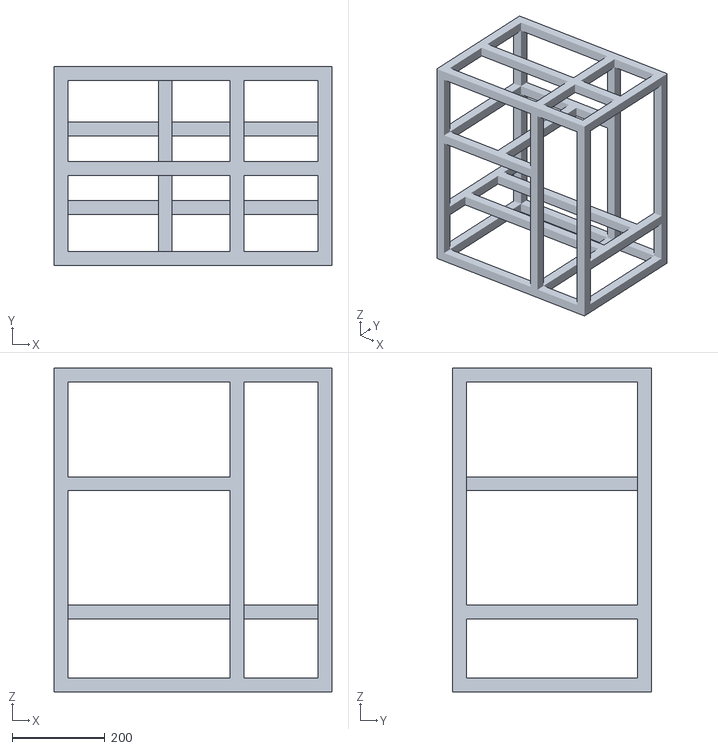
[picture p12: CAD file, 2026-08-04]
V2/parts/4_ORDER_frame_3030_assembly.stl
600.0 x 430.0 x 700.0

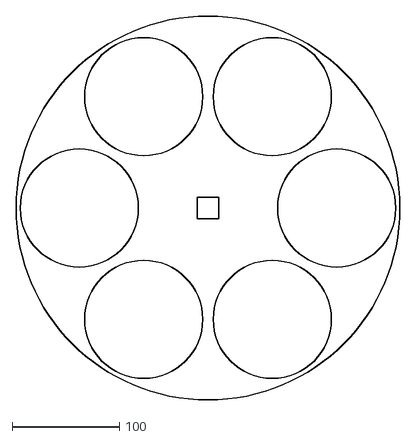
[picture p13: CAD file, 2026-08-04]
docs/hub_layer_110_2.dxf
358.0 x 358.0

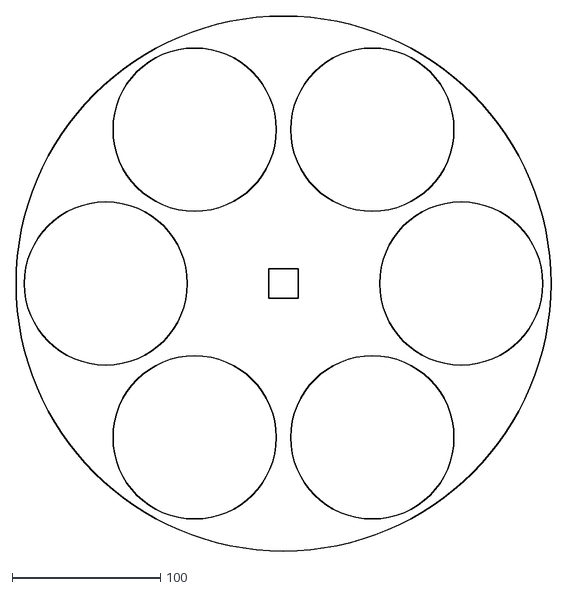
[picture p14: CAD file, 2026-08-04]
docs/hub_middle_rim_110_2.dxf
361.3 x 361.3

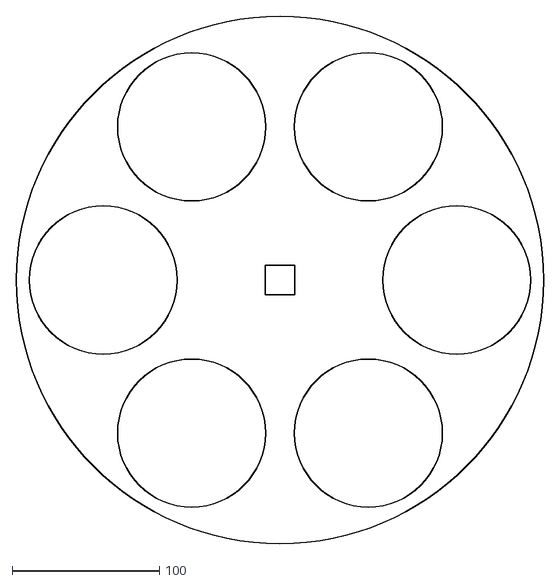
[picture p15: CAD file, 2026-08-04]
docs/hub_layer_100_5.dxf
358.0 x 358.0

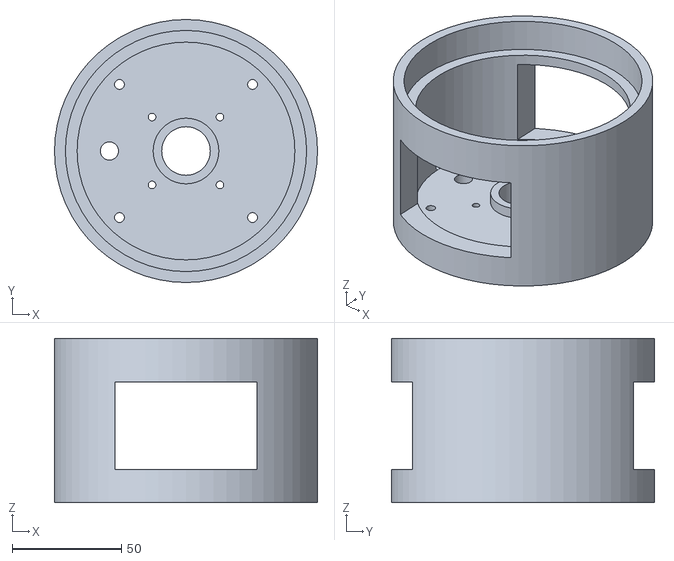
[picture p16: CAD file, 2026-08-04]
V2/parts/2_3DPRINT_cup_cage.stl
120.2 x 120.2 x 75.0

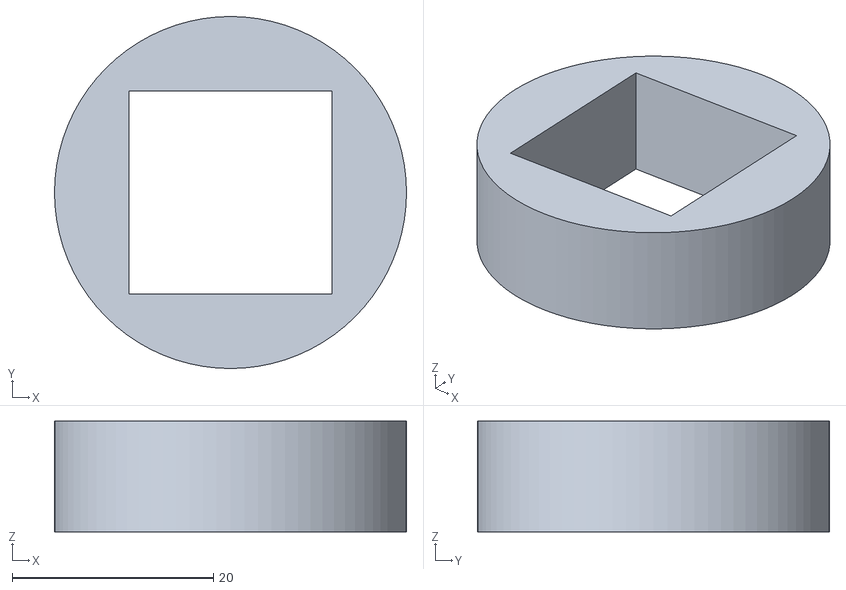
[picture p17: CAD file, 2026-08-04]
V2/parts/2_3DPRINT_hub_upper_boss.stl
35.0 x 35.0 x 11.0

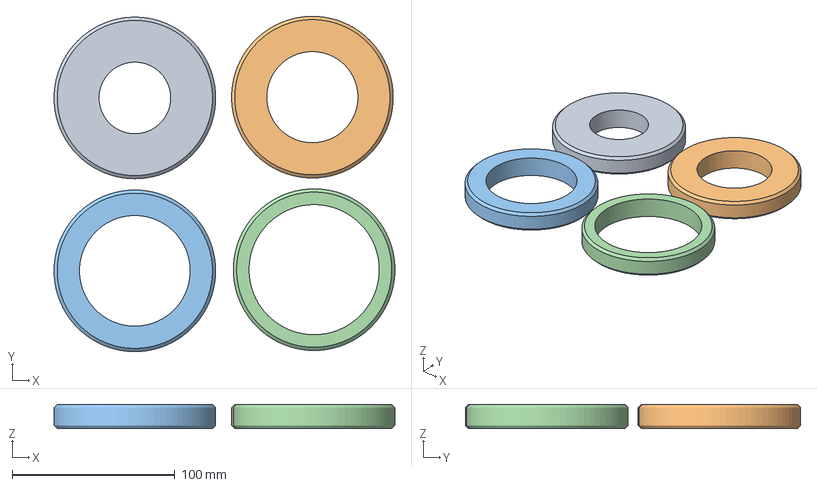
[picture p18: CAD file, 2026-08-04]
V2/parts/4_ORDER_rings_6types_994.3mf
209.6 x 206.2 x 15.0 mm
4_ORDER_rings_6types_994.stl_3
4_ORDER_rings_6types_994.stl_4
4_ORDER_rings_6types_994.stl_5
4_ORDER_rings_6types_994.stl_6

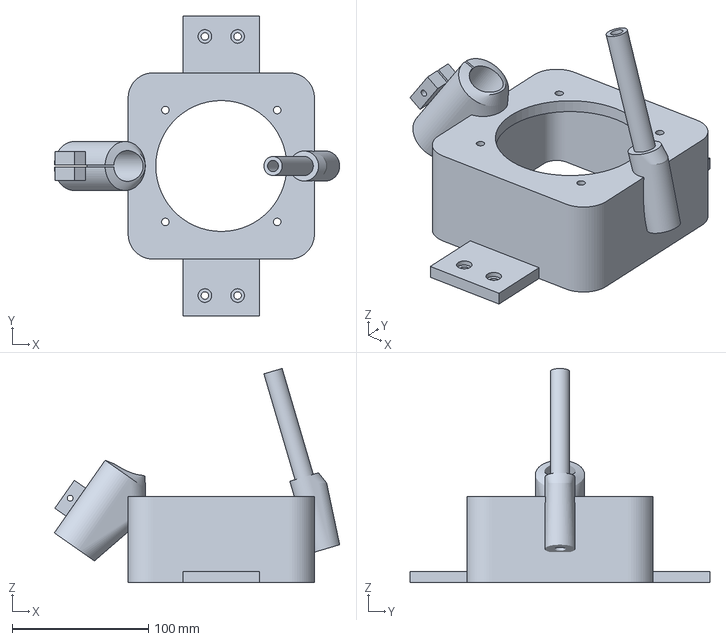
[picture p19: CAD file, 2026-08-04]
V2/parts/4_ORDER_cup_piston.3mf
209.3 x 220.0 x 157.0 mm

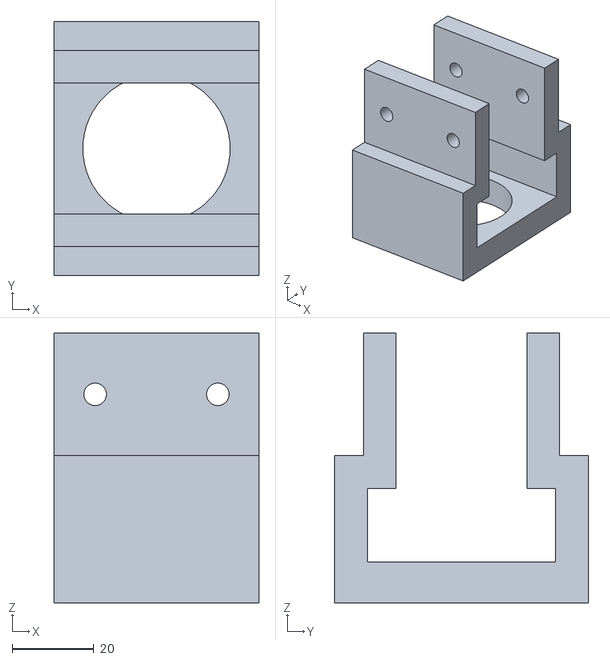
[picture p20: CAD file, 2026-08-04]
V2/parts/2_3DPRINT_bracket_upper_shaft.stl
50.0 x 62.0 x 66.0

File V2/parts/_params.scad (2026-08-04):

// =========================================================================
// 공유 파라미터 (모든 개별 부품 파일에서 include)
// 메인 어셈블리: cup_z_x_catrage_frame_water_mic_anti_3030.scad 에서 추출
// 프레임: 600 × 420 × 700mm (3030 프로파일, Y=0 대칭)
// =========================================================================

$fn = 60;  // 부품 출력용 고해상도
GLOBAL_TOLERANCE = 0.2;

// --- [1] 하부 기성품 및 원통 파라미터 ---
X_RAIL_LEN = 290.0;
X_BLOCK_W = 30.0; X_BLOCK_L = 32.0;   // 신규 X슬라이더 블록 (폭 30mm × 길이 32mm)
X_PITCH_X = 20.0; X_PITCH_Y = 20.0;   // 체결 홀 피치 (20 × 20mm, M3 나사탭 4개)
X_RAIL_W = 30.0;  X_RAIL_H = 20.0;   // 레일 폭 30mm (레일 바닥~블록 윗면 높이 29mm 반영)
X_TOTAL_H = 29.0;                    // 레일 바닥에서 슬라이더 블록 윗면까지의 높이

MOTOR_W = 42.0;      MOTOR_PITCH = 31.0; MOTOR_HOLE_D = 3.5;    
MOTOR_BOSS_D = 22.0; MOTOR_BOSS_H = 2.0; SCREW_D = 8.0;         
MOT_BODY_L = 41.0;   SHAFT_L = 24.0;     // 실측 NEMA17 몸통 41mm / 축 돌출 24mm

CUP_ID = 99.5;  CUP_WALL = 5.0; CUP_OD = 110.0;     // 아크릴 원통 OD110/ID100
CUP_H = 180.0;   CAGE_H = 60.0;  FLOOR_H = 10.0; PISTON_H = 20.0;     

LIP_D = 30.0;    LIP_H = 5.0;    LEAK_DRAIN_D = 4.0;    
GUIDE_PIPE_D = 8.0; BUSHING_OD = 12.0; BUSHING_H = 8.0;       
DRAIN_RADIUS = 35.0; DRAIN_D = 8.0;        

Y_OFFSET = 85.0; BRKT_H = 12.0; BRKT_D = 122.0; BRKT_ID = 62.0; Z_MOUNT_PCD = 86.0;   

// --- [2] 아크릴 파이프 및 상부 카트리지 ---
ACRYL_ID = 100.0; ACRYL_T = 5.0; ACRYL_OD = ACRYL_ID + (ACRYL_T * 2);  // OD110 (아크릴집 106 재고없음 → 컵과 동일 규격)

REVOLVER_PCD = 240.0;     // 인접 카트리지 웹 9.8mm 확보 (OD110 대응, 230→240)
CARTRIDGE_OD = REVOLVER_PCD + ACRYL_OD + 8; 
TOP_PLATE_H = 15.0;       // 아크릴 15T 통판 (보스홀 단 깊이 10mm)

HUB_D = 60.0;            
SHAFT_D = 12.0;          
HUB_WALL = 4.0;          
HUB_H = 15.0;             // 아크릴 5T × 3장 적층 — 파이프 130mm 대응
POCKET_DEPTH = 5.0;
MID_HUB_Z = 63.5;          // 중단 허브 하면 Z (벨트 중심 Z=71.0mm 정렬, 풀리 상단 Z=75.0mm = 축상단-1mm)
UPPER_HUB_Z = 135.0;       // 상단 허브 하면 Z (전체 135+15=150 유지)
BOSS_OD = 35.0;
BOSS_H = 11.0;             // 보스11 + 와셔1 = 12, 리세스10 → 허브 2mm 공중

// --- [3] GT2 벨트 구동 시스템 ---
GT2_PITCH     = 2.0;
GT2_BELT_W    = 6.0;
BIG_PULLEY_TEETH = 566;
BIG_PULLEY_PD = BIG_PULLEY_TEETH * GT2_PITCH / PI;
BIG_PULLEY_OD = BIG_PULLEY_PD + 1.0;
SMALL_PULLEY_TEETH = 20;
SMALL_PULLEY_PD = SMALL_PULLEY_TEETH * GT2_PITCH / PI;
SMALL_PULLEY_OD = SMALL_PULLEY_PD + 1.0;

BELT_MOTOR_X = -300;
BELT_MOTOR_Y = -155.5;
BRKT_MOTOR_H = 25.0;
BRKT_MOTOR_W = 45.0;        // 브래킷 폭 45mm (프로파일 간섭 회피 복원)
SLOT_LEN = 10.0;
FLAG_W = 15.0;  FLAG_H = 8.0;  FLAG_T = 1.5;

X_POS_MEASURE = 170.0;   // 측정 브래킷 X좌표 (X_M~X_R 정중앙, X대칭)

// --- [4] 3030 프레임 경계 (600×430×700mm) ---
PF = 30;             // 3030 알루미늄 프로파일
WASHER_T = 1.0;     

X_L = -320;
X_M = 60;
X_R = 250;
Y_F = -210;          // 전방 (대칭: -210+30=-180, Y=0 중심)
Y_B = 180;           // 후방 (대칭: 180+30=210, Y=0 중심) — 메인파일과 동기화

Z_BOT = -480;
Z_RAIL = -322;
Z_MID = -TOP_PLATE_H - PF;
Z_TOP = 220;

SUPPORT_PILLAR_H = Z_TOP - PF;

SHAFT_SQ = 20;       // 2020 사각 회전축

// 사각 축 홀 크기
SQ = SHAFT_SQ + GLOBAL_TOLERANCE;  // 20.2mm

// --- 리볼버/컵 축 정렬 (보스홀=판 중심에 리볼버 정렬) ---
REVOLVER_CX = (X_L + X_M + PF)/2;        // 판 중심 = 보스홀 = 리볼버 회전축 (-115)
DROP_X      = REVOLVER_CX + REVOLVER_PCD/2;  // 링 드롭 / 컵 적재 축 (+5)

FLANGE_Z = 52.0;       // 모터 전면 안착 높이 (Z=52mm -> 축 상단 Z=76mm, 풀리 결합)

// --- [5] 모터 체결홀 (이미 제작 완료된 15T 상판 원본 도면 수치 100% 유지) ---
MOTOR_BOLT_PITCH     = 25.0;      // Y피치 (Y = ±12.5mm)
MOTOR_BOLT_X_NOMINAL = X_L + 55;  // 1열: 상판 좌단 55 (모터축 기준 +35mm = X=-265mm)
MOTOR_BOLT_X_SHIFT   = X_L + 40;  // 2열: 상판 좌단 40 (모터축 기준 +20mm = X=-280mm)

// 모터 마운트 볼트 카운터보어 (단볼트용 — 브래킷 두께 25 중 깊게 파냄)
MOTOR_CB_D     = 6.5;            // M3 캡볼트 머리 클리어런스
MOTOR_CB_DEPTH = 19;             // 카운터보어 깊이 (잔여 통과 6mm → M3×10 단볼트)

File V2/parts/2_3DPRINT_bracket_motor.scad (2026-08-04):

// =========================================================================
// [부품] 모터 브래킷 (양측 수직벽 포털 아치형 모터 마운트 브래킷)
// 가공: 3D 프린팅 (PLA)
// 원점: 브래킷 바닥면(상판 접촉면) = Z=0, 모터 축 = XY 원점
// 특징: 좌/우 양측 수직벽(내경 43mm) + 상부 천장(Z=52mm) + 기존 가공 상판 체결 정렬
// =========================================================================
include <_params.scad>

module bracket_motor() {
    BLOCK_W = 45.0;       // Y방향 폭 (45mm)
    LEFT_WALL_T = 5.0;    // 좌측 수직벽 두께 (5mm)
    RIGHT_WALL_T = 7.0;   // 우측 수직벽 두께 (7mm)
    LEFT_X_START = -26.5; // 좌측 수직벽 외단 (-26.5mm)
    LEFT_X_END   = -21.5; // 좌측 수직벽 내단 (-21.5mm -> 42mm 모터 좌단 -21mm와 0.5mm 유격)
    RIGHT_X_START = 21.5; // 우측 수직벽 내단 (+21.5mm -> 42mm 모터 우단 +21mm와 0.5mm 유격)
    RIGHT_X_END   = 28.5; // 우측 수직벽 외단 (+28.5mm)
    FLANGE_Z = 52.0;      // 모터 전면 안착 천장 높이 (Z=52mm -> 축 상단 Z=76mm)
    PLATE_T = 6.0;        // 상부 천장 및 바닥 날개 두께 (6mm)
    TOTAL_H = FLANGE_Z + PLATE_T; // 브래킷 전체 높이 (58mm)
    BRKT_EXT = 30.0;      // 우측 체결 날개 연장 길이 (30mm)

    difference() {
        union() {
            // [1] 상부 천장 플랜지 (X = -26.5 ~ +28.5mm, Y = -22.5 ~ +22.5mm, Z = 52~58mm)
            translate([LEFT_X_START, -BLOCK_W/2, FLANGE_Z])
                cube([RIGHT_X_END - LEFT_X_START, BLOCK_W, PLATE_T]);

            // [2-1] 좌측 수직 지지 벽 (X = -26.5 ~ -21.5mm, Z = 0~52mm, 내경 43mm 확보)
            translate([LEFT_X_START, -BLOCK_W/2, 0])
                cube([LEFT_WALL_T, BLOCK_W, FLANGE_Z]);

            // [2-2] 우측 수직 지지 벽 (X = +21.5 ~ +28.5mm, Z = 0~52mm, 내경 43mm 확보)
            translate([RIGHT_X_START, -BLOCK_W/2, 0])
                cube([RIGHT_WALL_T, BLOCK_W, FLANGE_Z]);

            // [3] 하부 상판 체결 바닥 날개 (X = -26.5 ~ +52.5mm, 두께 6mm)
            translate([LEFT_X_START, -BLOCK_W/2, 0])
                cube([BLOCK_W/2 + BRKT_EXT - LEFT_X_START, BLOCK_W, PLATE_T]);
        }

        // [4] NEMA 17 전면 마운트 관통홀 (31mm 피치, M3 관통)
        for(dx = [-MOTOR_PITCH/2, MOTOR_PITCH/2])
            for(dy = [-MOTOR_PITCH/2, MOTOR_PITCH/2]) {
                translate([dx, dy, FLANGE_Z - 1]) cylinder(d=MOTOR_HOLE_D, h=PLATE_T + 2, $fn=30);
                // 상면 카운터보어 (M3×10mm 볼트 머리 매립, 깊이 3.5mm)
                translate([dx, dy, TOTAL_H - 3.5]) cylinder(d=6.5, h=4.0, $fn=30);
            }

        // [5] 중앙 축 관통홀 (모터 보스 ø22mm 및 샤프트)
        translate([0, 0, FLANGE_Z - 1]) cylinder(d=MOTOR_BOSS_D + 1, h=PLATE_T + 2, $fn=30);

        // [6] 상판 체결 장공 슬롯 (우측벽 X=+28.5mm와 미세 유격 간섭 0% 정밀 보정, X = +32 ~ +42mm)
        for(dy = [-MOTOR_BOLT_PITCH/2, MOTOR_BOLT_PITCH/2])
            hull() {
                translate([32, dy, -2]) cylinder(d=4.5, h=PLATE_T + 4, $fn=30);
                translate([42, dy, -2]) cylinder(d=4.5, h=PLATE_T + 4, $fn=30);
            }
    }
}

// 단품 직접 실행 시 3D 렌더링
bracket_motor();

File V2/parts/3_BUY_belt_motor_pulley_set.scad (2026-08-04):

// =========================================================================
// [구매] 벨트 구동 모터 + 풀리 세트 (타워 마운트 높이 반영)
// 구매: NEMA17 (42×42×43) + GT2 20T 풀리 + GT2 타이밍벨트
// 원점: 브래킷 바닥면(상판 접촉면) = Z=0, 축 상향
// =========================================================================
include <_params.scad>

FLANGE_Z = 52.0;    // 타워 플랜지 높이 (모터 전면 위치 Z=52mm -> 축 상단 Z=76mm)
MOT_BODY_L = 41.0;  // 실측 NEMA 17 모터 몸통 높이 (41mm)
SHAFT_L = 24;
PULLEY_Z = 67.0;    // GT2 풀리 바닥 Z=67.0mm (플랜지 포함 풀리 상단 Z=75.0mm = 축 상단 Z=76.0mm보다 1.0mm 낮춤)

// ── ① NEMA 17 모터 본체 (전면이 Z=42mm에 안착, 몸통은 아래로 위치) ──
color([0.1, 0.1, 0.1])
    translate([-MOTOR_W/2, -MOTOR_W/2, FLANGE_Z - MOT_BODY_L])
        cube([MOTOR_W, MOTOR_W, MOT_BODY_L]);

// ── ② 모터 보스 (ø22 × 2mm, Z=42mm 상면) ──
color([0.25, 0.25, 0.25])
    translate([0, 0, FLANGE_Z])
        cylinder(d=MOTOR_BOSS_D, h=MOTOR_BOSS_H);

// ── ③ 모터 축 (상면에서 위로 돌출, Z=42~66mm) ──
color([0.7, 0.7, 0.7])
    translate([0, 0, FLANGE_Z])
        cylinder(d=5, h=SHAFT_L);

// ── ④ GT2 20치 풀리 (Z=73.5mm, 벨트 라인 정렬) ──
color([0.8, 0.75, 0.1]) translate([0, 0, PULLEY_Z]) difference() {
    union() {
        cylinder(d=SMALL_PULLEY_OD, h=GT2_BELT_W + 2);
        cylinder(d=SMALL_PULLEY_OD + 4, h=1);               // 하부 플랜지
        translate([0, 0, GT2_BELT_W + 1])
            cylinder(d=SMALL_PULLEY_OD + 4, h=1);           // 상부 플랜지
    }
    translate([0, 0, -1]) cylinder(d=5.2, h=GT2_BELT_W + 4);
}

// ── ⑤ 배선 커넥터 (모터 하면) ──
color([0.9, 0.9, 0.9])
    translate([-6, -5, FLANGE_Z - MOT_BODY_L - 3])
        cube([12, 10, 3]);

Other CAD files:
V2/parts/4_ORDER_rings_9956.gcode.3mf
V2/parts/4_ORDER_rings_9932.gcode.3mf
V2/parts/4_ORDER_rings_6types_994.gcode.3mf
V2/parts/2_3DPRINT_bracket_motor.gcode.3mf
V2/parts/4_ORDER_rings_9944.gcode.3mf
V2/parts/4_ORDER_rings_9980.gcode.3mf
V2/parts/2_3DPRINT_cup_cage.gcode.3mf
V2/parts/4_ORDER_rings_9968.gcode.3mf
V2/parts/4_ORDER_cup_piston.gcode.3mf
V2/parts/3_BUY_z_motor_screw_set.scad
V2/3030.scad
V2/parts/2_3DPRINT_bracket_measurement.scad
V2/parts/2_3DPRINT_bracket_measurement.stl
V2/parts/2_3DPRINT_bracket_motor.3mf
V2/parts/2_3DPRINT_bracket_motor.stl
V2/parts/2_3DPRINT_bracket_upper_shaft.scad
V2/parts/2_3DPRINT_clamp_boss_x2.3mf
V2/parts/2_3DPRINT_clamp_boss_x2.gcode.3mf
V2/parts/2_3DPRINT_clamp_boss_x2.scad
V2/parts/2_3DPRINT_clamp_boss_x2.stl
V2/parts/2_3DPRINT_cup_cage.scad
V2/parts/2_3DPRINT_flange_nut.scad
V2/parts/2_3DPRINT_flange_nut.stl
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

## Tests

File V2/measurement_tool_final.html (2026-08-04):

🎙️

## Acoustic Measurement Tool

마이크 접근 권한이 필요합니다.
아래 버튼을 눌러 마이크를 연결하세요.

🎙️ 마이크 연결 및 시작

🎙️ Acoustic Measurement Tool

입력 장치:

🎤 녹음 / 분석 📊 스윕 전달함수 💧 이산 물채움

### ⚙️ FFT 설정

FFT 크기

윈도우 함수

스펙트로그램 오버랩 75%

### 🔎 포먼트 (LPC)

LPC 차수 20

최대 포먼트 주파수 (Hz)

최대 대역폭 (Hz) 400

### 🔊 스윕 설정

시작 주파수 (Hz)

끝 주파수 (Hz)

스윕 길이 (초) 2.0

볼륨 80%

### 📥 내보내기

📦 세션 JSON

⏺ 녹음 시작 ▶ 재생 📂 파일 열기 ● 00:00.0

📈 파형 (Waveform) 💾 WAV

🌈 스펙트로그램 — 클릭하여 해당 시점 분석 📥 CSV

📊 FFT 스펙트럼 📥 CSV

### 🎯 포먼트 추출 결과

📥 CSV

1

레퍼런스 녹음

2

측정 녹음

3

전달함수 분석

🔊

스피커 앞에 컵 없이 마이크만 배치한 상태에서
아래 버튼을 눌러 레퍼런스 녹음을 시작하세요.

반복 촬영 횟수(중앙값 결합)

▶ 레퍼런스 녹음

또는 이미 녹음된 레퍼런스 WAV 불러오기(여러 개 선택 시 중앙값 결합):

📂 레퍼런스 WAV 불러오기

이 세션과 같은 스윕 설정(시작/끝 주파수·길이·음량)으로 녹음된 WAV여야 정확합니다.

또는 저장된 세션 번들 불러오기(레퍼런스+측정 한 쌍):

📂 세션 번들 (.zip) 불러오기

레퍼런스 녹음 미리보기

💾 WAV ↻ 다시 녹음 다음 →

🥛

측정할 컵을 스피커 앞에 놓은 후
아래 버튼을 눌러 측정 녹음을 시작하세요.

반복 촬영 횟수(중앙값 결합)

▶ 측정 녹음

또는 이미 녹음된 측정 WAV 불러오기(여러 개 선택 시 중앙값 결합):

📂 측정 WAV 불러오기

이 세션과 같은 스윕 설정(시작/끝 주파수·길이·음량)으로 녹음된 WAV여야 정확합니다.

측정 녹음 미리보기

💾 WAV ↻ 다시 녹음 전달함수 계산 →

표시: 📡 레퍼런스 🥛 측정 📊 전달함수

📊 주파수 응답 비교

🔔 임펄스 응답 h(t)

### 🎯 전달함수 포먼트 (공명 주파수)

🔄 새 측정 📦 세션 번들 (.zip) 📥 전달함수 CSV

💧

이산 물채움 측정 세션을 시작합니다.
먼저 레퍼런스 녹음을 하고, 이후 물을 단계적으로 추가하며 측정합니다.

균등 투입 (매 스텝 동일한 양)

1회 투입량 (mL)

예상 총 스텝 수

스텝별 투입량 (mL, 쉼표로 구분)

Step 0(빈 컵) 다음부터 각 스텝에서 추가로 붓는 양입니다. 입력한 개수만큼 스텝이 만들어집니다(빈 컵 스텝 제외).

레퍼런스 반복 촬영 횟수 (중앙값 결합)

스텝별 반복 촬영 횟수 (중앙값 결합)

스윕을 여러 번 쏘고 주파수별 중앙값을 취해 순간 글리치(찍힘)를 제거합니다. 1로 두면 기존과 동일하게 1회만 측정합니다.

🚀 세션 시작

또는 저장된 세션 번들 불러오기:

📂 세션 번들 (.zip) 불러오기

🔊

Step: 레퍼런스 — 컵 없이 마이크만 놓고 녹음하세요

▶ 레퍼런스 녹음 ↻ 다시 녹음 다음 스텝 → 📊 결과 보기

Step 1/20

🥛

빈 컵을 놓고 녹음하세요 (누적: 0 mL)

▶ 이 스텝 녹음 ↻ 다시 녹음 다음 스텝 → 📊 결과 보기

전달함수

### 📊 이산 물채움 측정 결과

수위별 전달함수 워터폴

🌈 수위별 전달함수 스펙트로그램 + 포먼트 추적

🔍 스텝 탐색:

💾 WAV 📥 전달함수 CSV 📥 포먼트 CSV

📈 파형

📊 전달함수

🎯 포먼트

🔬 A0 레퍼런스 교체 실험 — 이미 녹음한 스텝은 그대로 두고, 레퍼런스만 바꿔가며 비교·내보내기

조건 라벨(파일명에 사용, 예: 무_흡음유)

반복 촬영 횟수 🎤 새 레퍼런스 녹음 📂 레퍼런스 WAV 불러오기

WAV로 불러올 경우, 이 세션과 같은 스윕 설정(시작/끝 주파수·길이·음량)으로 녹음된 파일이어야 정확합니다. 새로 녹음하면 현재 사이드바의 스윕 설정을 그대로 사용합니다.

현재 레퍼런스: 세션 시작 시 녹음한 것 그대로 (아직 교체 안 함)

📊 현재 레퍼런스 기준 비율 미리보기 (마지막 스텝)

📥 이 레퍼런스로 비율 JSON (app.py용) 📥 개별 테이크 원본 스펙트럼 전체 (zip, 재현성 분석용)

🔄 새 세션 📦 세션 번들 (.zip) 📥 전체 CSV 🐍 app.py용 JSON

대기 중

🎤 -- Hz

⏱ 0.0s

📊 FFT: 2048

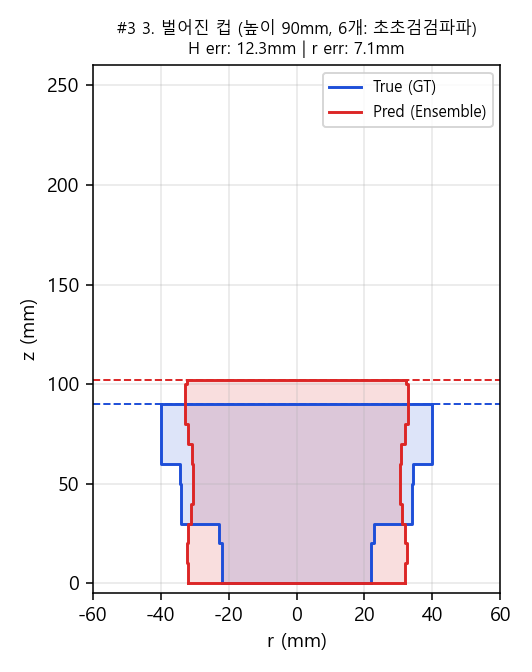
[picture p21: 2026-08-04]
V2/measured_plots/cup_03.png

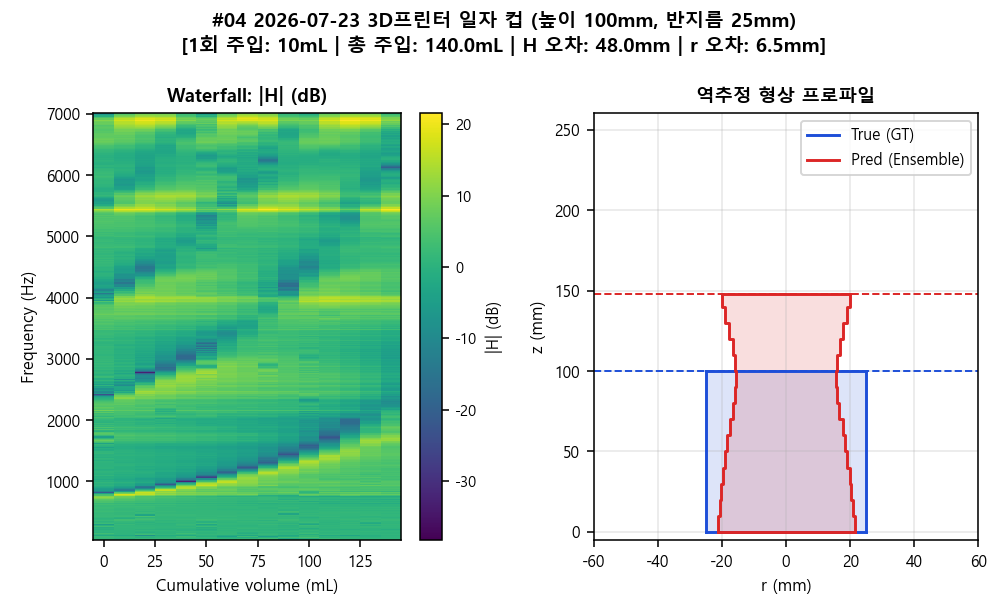
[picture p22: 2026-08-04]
V2/measured_plots_v4/cup_v4_04.png

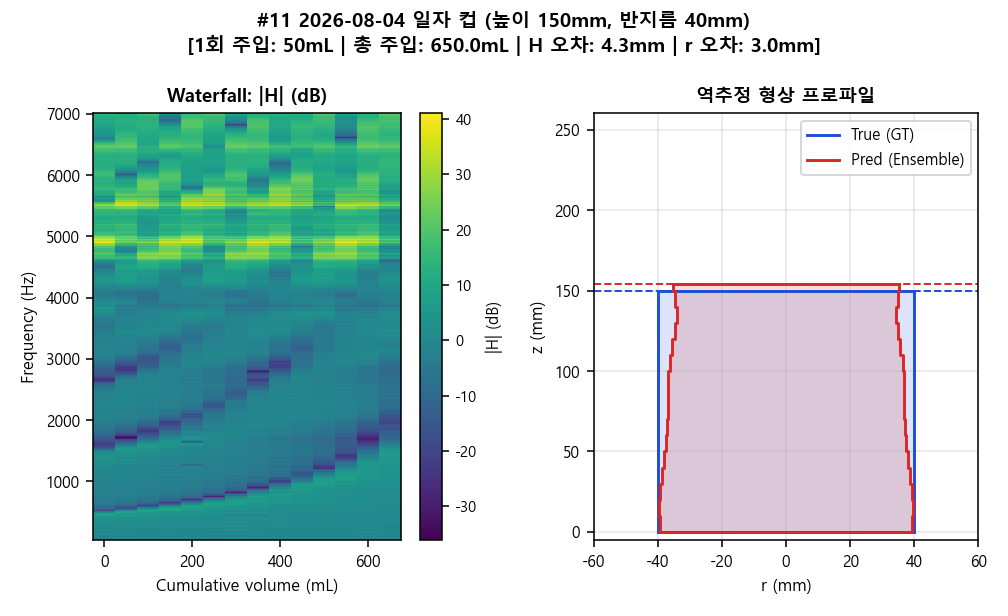
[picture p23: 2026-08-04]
V2/measured_plots_v4/cup_v4_11.png

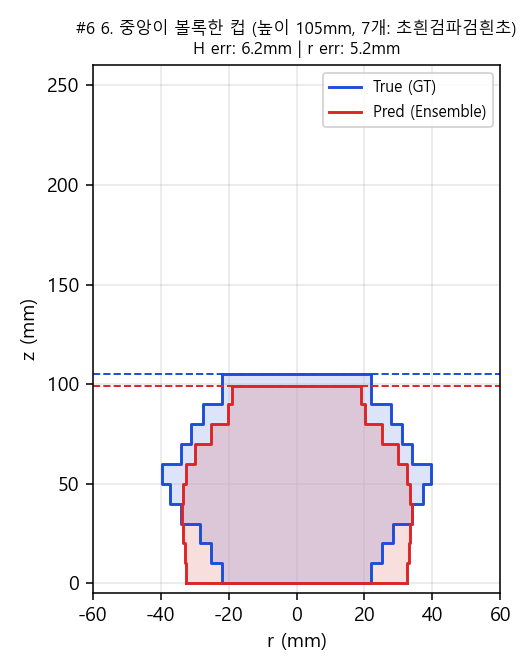
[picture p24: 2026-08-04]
V2/measured_plots/cup_06.png

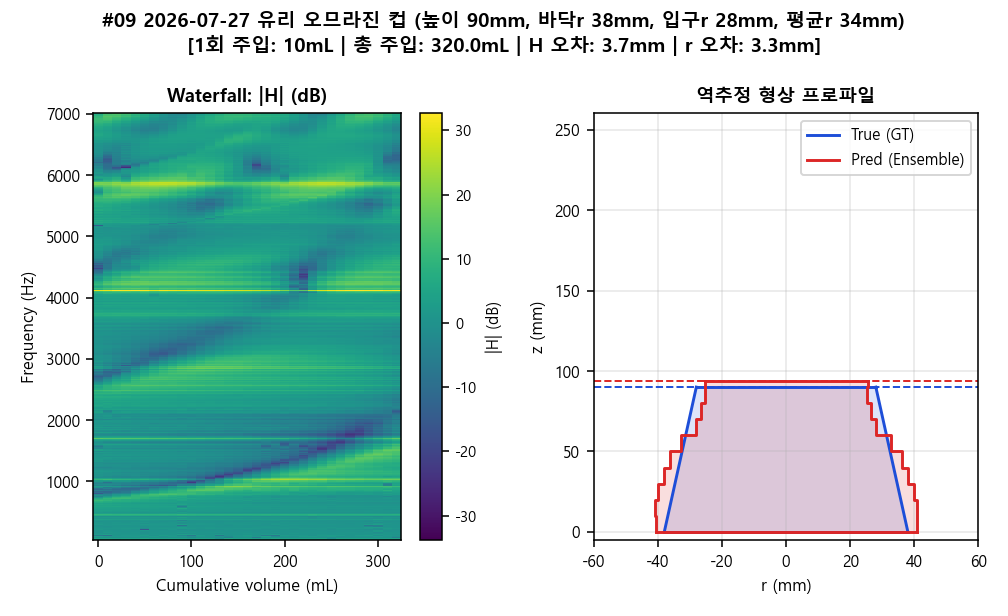
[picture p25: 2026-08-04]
V2/measured_plots_v4/cup_v4_09.png

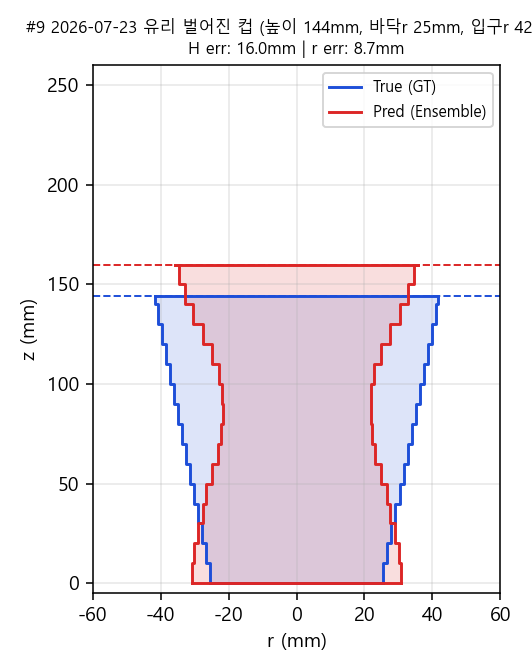
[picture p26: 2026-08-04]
V2/measured_plots/cup_09.png

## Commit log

2026-08-04 Initial commit: Acoustic Shape Reconstruction V2 project
    [base_ratio_smoke_trainlog.csv, hub_layer_100_5.dxf, hub_layer_110_2.dxf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]
2026-08-04 Update gitignore filter rules to isolate V2 modules
2026-08-04 Add OpenSCAD 3D CAD drawing models under v2/parts
    [2_3DPRINT_bracket_measurement.scad, 2_3DPRINT_bracket_measurement.stl, 2_3DPRINT_bracket_motor.3mf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]
2026-08-05 feat: TTR 버전 레지스트리 구축 및 UI/배치 평가 스크립트 개선
2026-08-05 feat: TTR v1 (다중 초깃값 선별기 및 딥 앵커 옵션) 구현 및 레지스트리 등록
